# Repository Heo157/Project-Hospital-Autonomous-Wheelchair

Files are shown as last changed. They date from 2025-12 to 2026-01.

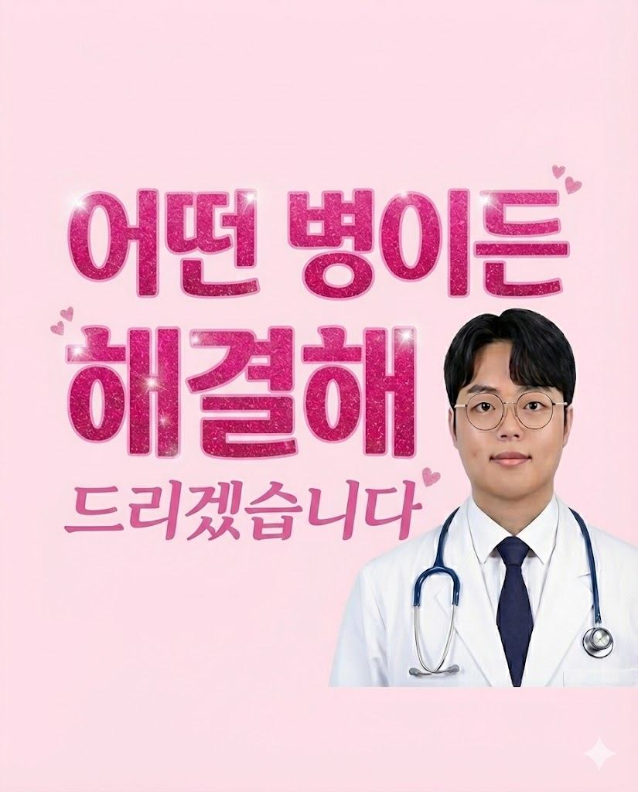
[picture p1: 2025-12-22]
Hospital_WithSTM/Hospital_STM/TouchGFX/assets/images/jinkyoung.png

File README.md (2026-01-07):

# 🏥 Hospital Autonomous Wheelchair Robot  

> **요약**  
> TurtleBot3 Burger 플랫폼에 3D 프린팅 휠체어 구조물을 장착하고,  
> **LiDAR SLAM 기반 자율주행(ROS2/Nav2)** + **중앙 서버/DB 배차 시스템** + **Qt 터치 키오스크(외래 호출)** + **STM32U5(초음파/압력 + Touch-GFX UI)** 를 결합해  
> 병원 환경에서 **환자 호출 → 탑승 확인 → 목적지 이동 → 도착 알림 → 하차/대기/충전** 흐름을 구현하는 프로젝트입니다.
>
> Youtube 영상 : https://youtu.be/OP_KvQtHlb4

---

## 📌 1. 프로젝트 목표

- 병원에서 거동이 불편한 환자가 휠체어를 쉽게 호출하고 이동할 수 있도록 지원
- **외래 환자**는 **터치 키오스크(Qt)** 로 호출
- **입원 환자**는 간호사가 **간호사용(QT)** 로 호출
- 자율주행은 **LiDAR SLAM + Nav2** 로 수행
- **STM32U5G9J-DK2 보드**로:
  - LiDAR가 감지하기 어려운 **낮은 높이 장애물**을 초음파로 감지
  - **압력 센서**로 환자 탑승/하차를 감지하여 서버/DB에 반영
  - 보드 내장 **Touch-GFX**에서 로봇 상태/토픽값을 실시간 UI로 표시

---

## 🔧 2. 하드웨어 구성 

### ✅ Robot Side


### ✅ STM32 Side


---

## ✨ 3. 핵심 기능

### ✅ 자율주행
- SLAM으로 맵 생성
- AMCL로 위치 추정
- Nav2로 경로 계획 및 목표 지점 이동

### ✅ 외래 호출: Qt 터치 키오스크
- 외래 환자가 직접 터치 키오스크에서 “휠체어 호출”
- 출발/목적지 선택(또는 스테이션 기준 호출)
- 호출 정보는 서버/DB에 저장되고, 배차 로직이 로봇을 할당

### ✅ 입원 환자 호출/이동
  - 간호사가 필요에 따라 QT에서 환자에게 휠체어 배정 
  - 병동/병실 등 미리 등록된 위치로 휠체어 로봇 배차 및 이동
    
### ✅ 서버/DB 기반 배차
- DB의 호출 큐(call queue)를 기반으로
  - 가용 로봇 탐색
  - 우선순위 배정
  - 로봇에 start/goal 좌표 전달
  - 로봇 상태를 DB에 지속 기록

### ✅ STM32U5 보드 + Touch-GFX UI
- 초음파(IUM-100): **하단 장착** → 낮은 장애물 감지용
- 압력(FSR): **seat_detected** → 탑승 감지용
- Touch-GFX UI에 ROS 토픽 기반 상태 표시

---

## 🗺️ 4. 동작 시나리오 

### 4.1 외래 환자 호출(키오스크)
1. 외래 환자가 **Qt 키오스크**에서 휠체어 호출
2. 키오스크가 서버/DB에 호출 등록(call queue insert)
3. 서버 Dispatch가 가용 로봇을 선택하여 배차
4. 로봇은 출발지 → 목적지로 Nav2 goal 이동
5. 도착 시 서버/관리자 UI에 알림

### 4.2 입원 환자 호출(병동/병실 기반)
1. 간호사/관리자가 호출(병실/병동 선택)
2. 서버가 DB의 위치(map_location) 좌표를 참조
3. 로봇 배차 후 해당 위치로 이동

### 4.3 탑승/하차 판단(압력 센서)
- STM32U5의 FSR 압력 센서로 `seat_detected = 1/0` 판별
- Raspberry Pi4가 이를 수신하고 서버에 전달하여 DB에 기록

### 4.4 하단 장애물 안전(초음파)
- LiDAR는 보통 바닥 가까운 낮은 장애물을 놓칠 수 있음
- STM32U5 초음파를 하단에 장착하여 `/ultra_distance_cm` publish
- 임계 거리 이하면:
    -Nav2 goal cancel/재계획(설계에 따라)

----

## 🧠 5. 시스템 아키텍처 

### 1) 전체 시스템 아키텍처 


- **Application (Qt)**  
  - 관리자용 Qt / 외래환자용 Qt  / 간호사용 Qt 
- **Database (MariaDB/SQL)**  
  - `robot_status`, `call_queue`, `map_location` 등을 통해 상태 저장 및 배차 데이터 관리
- **Central Server (TCP, C)**  
  - 로봇 접속 관리, 상태 수집, 명령 전달, 배차 로직 수행
- **Platform (ROS2)**  
  - 로봇의 자율주행, 센서 토픽 처리, 서버-로봇 브리지 연동
- **Hardware**  
  - TurtleBot3 Burger + STM32U5 모듈(센서/디스플레이)

---

### 2) 다중 로봇 확장형 배차 구조 (robot_status 기반 최대 N대 운영)


본 시스템은 **DB의 `robot_status` 테이블**을 중심으로 로봇을 관리합니다.

- 로봇 하드웨어가 추가 되다면
  - 서버는 `robot_status`의 `robot_id`(또는 name)를 기준으로 **로봇 호스트를 등록**
  - 로봇 상태를 주기적으로 갱신하고,
  - 호출 큐(`call_queue`)와 매칭해 **배차/명령 할당**을 수행합니다.
- 즉, **로봇이 늘어나도 서버/DB 구조는 동일**하며,
  - `robot_status` 레코드 수만 증가하는 형태로 **최대 100대 까지 확장 가능한 구조**를 목표로 설계했습니다.

---

### 3) STM32U5 + TouchGFX  연동 구조 (ROS 토픽 표시 + 센서 토픽 생성)



STM32U5는 단순 센서 보드가 아니라, **로봇 상태 표시(TouchGFX) + 센서 모듈** 역할을 수행합니다.

#### ✅ A. ROS → STM32U5(TouchGFX) 
Raspberry Pi 4(ROS2)에서 수신/발행 중인 주요 토픽을 STM32U5로 전달하여 TouchGFX에 표시합니다.

| Topic | 의미 | UI 표시 예시 |
|---|---|---|
| `/hostname/amcl_pose` | 맵 기준 현재 위치 | x, y, yaw |
| `/hostname/odom` | odom/속도 | v, w, 누적 |
| `/hostname/battery_state` | 배터리 상태 | %, charging |
| `/hostname/goal_pose` | 목표 좌표 | goal x, y |
| `/hostname/scan` | LiDAR 스캔 | min range |

#### ✅ B. STM32U5 센서 → ROS2 토픽 생성 → STM32U5(TouchGFX) 
STM32U5에 연결된 센서를 통해 ROS2로 전송하여 **추가 토픽을 생성**하고, 로봇 호스트명을 붙여 재발행 하고 STM32U5로 전달하여 TouchGFX에 표시합니다.

- STM32U5 센서 입력:
- | Topic | 의미 | UI 표시 예시 |
  |------|------|-------------|
  | `/hostname/ultra_distance_cm` | 초음파 거리(cm) | min 거리 |
  | `/hostname/seat_detected` | 탑승 감지(0/1) | Seated/Empty |

- 운영 관점:
  - 다중 로봇 환경에서 토픽 충돌을 막기 위해  
    `/<hostname>/ultra_distance_cm`, `/<hostname>/seat_detected` 처럼 **호스트명 구조로 재발행** 

---

## 6. 🧱 Database (MariaDB/MySQL)

### ✅ 주요 테이블 요약

#### 1) `call_queue` — 호출 대기열 (키오스크/시스템 호출 저장)

| 컬럼명 | 설명 | 예시 |
|---|---|---|
| `call_id`  | 호출 ID | 101 |
| `call_time`  | 호출 생성 시간 | 2025-12-31 12:34:56 |
| `caller_name` | 환자/호출자 이름 | "홍길동" |
| `start_loc` | 출발지(장소명 문자열) | "키오스크" |
| `dest_loc` | 목적지(장소명 문자열) | "정형외과" |
| `is_dispatched`  | 배차 여부 | 배차 여부(0/1)|
| `eta`  | 상태/예상 정보 | "이동중" |

#### 2) `map_location` — 장소명 → 좌표 매핑 테이블

| 컬럼명  | 설명 | 예시 |
|---|---|---|
| `location_id`  | 장소 ID | 12 |
| `location_name` | 장소명(문자열) | "진료실 2" |
| `x` | 맵 좌표 X | 1.25 |
| `y` | 맵 좌표 Y | -3.40 |

> 서버 배차 시 `call_queue.start_loc`, `call_queue.dest_loc`을 `map_location`에서 찾아 (x, y)로 변환합니다.

#### 3) `robot_status` — 로봇 상태 + 명령 채널(핵심 테이블)

| 구분 | 컬럼명  | 설명 |
|---|---|---|
| 식별 | `robot_id` | 로봇 고유 ID |
| 식별 | `name`  | 로봇 이름(서버가 로봇 구분에 사용) |
| 네트워크 | `ip_address` | 로봇 IP |
| 상태 | `op_status`  | `WAITING/HEADING/BOARDING/RUNNING/STOP/ARRIVED/EXITING/CHARGING/ERROR` |
| 전원 | `battery_percent` | 배터리 % |
| 전원 | `is_charging` | 충전 중 여부(0/1) |
| 현재 위치 | `current_x` | 현재 X |
| 현재 위치 | `current_y` | 현재 Y |
| 현재 방향 | `current_theta` | 현재 θ(yaw) |
| 시작 좌표 | `start_x`  | 배차된 출발지 X |
| 시작 좌표 | `start_y` | 배차된 출발지 Y |
| 목표 좌표 | `goal_x` | 배차된 목적지 X |
| 목표 좌표 | `goal_y` | 배차된 목적지 Y |
| 센서/기타 | `sensor` | 센서 상태/메모 |
| **명령** | **`order`** | **명령 존재 여부(서버: `order>0`이면 로봇에게 전송)** |
| 호출자 | `who_called` | 호출자 이름 저장 |

> `order`는 서버 → 로봇 명령 전달을 위한 “DB 기반 명령 채널” 역할입니다.

#### 4) `patient_info`, `disease_types` — 우선순위 배차(응급/질병/호출시간)

##### `patient_info` (환자 정보)

| 컬럼(예시) | 설명 |
|---|---|
| `name` | 환자 이름 |
| `disease_code` | 질병 코드 |
| `is_emergency` | 응급 여부(1이면 최우선) |
| `type` | 환자 타입(OUT/IN) |

##### `disease_types` (질병 우선순위 기준)

| 컬럼(예시) | 설명 |
|---|---|
| `base_priority` | 우선순위 점수(클수록 우선) |

✅ **배차 우선순위 정렬**

| 우선순위 | 기준 | 정렬 방향 |
|---|---|---|
| 1 | `is_emergency` | DESC (응급 먼저) |
| 2 | `base_priority` | DESC (점수 높은 질병 먼저) |
| 3 | `call_time` | ASC (먼저 온 호출 먼저) |

---
## 7. 지도
   


---

## 🧰 8. 기술 스택

<div align="center">

<!-- UI -->


<br/>

<!-- Backend -->




<br/>

<!-- Core -->




<br/>

<!-- Hardware -->




<br/>

</div>

---

## 👥9. 팀원 소개 

| &nbsp;&nbsp;&nbsp;&nbsp;이름&nbsp;&nbsp;&nbsp;&nbsp; | &nbsp;&nbsp;&nbsp;&nbsp;역할&nbsp;&nbsp;&nbsp;&nbsp; | 파트 | 담당 기능(요약) | 사용 기술/도구 |
| :---: | :---: | :--- | :--- | :--- |
| **허진경** | 팀장 | Robot / ROS | TurtleBot3 자율주행(ROS2/Nav2/SLAM) 통합, <br>C 서버와 ROS 연결 노드, 미션 수행 로직 구현| ROS2, Nav2, SLAM |
| **강송구** | 부팀장 | Server / DB / Qt / Touch-GFX | C 서버 구현, MariaDB 스키마/쿼리 설계,<br>로봇 상태 저장/배차 로직, ROS 토픽 → Touch-GFX UI 표시 | C(Socket), MariaDB / MySQL, Touch-GFX(STM32) |
| **김선곤** | 팀원 | Qt / Touch-GFX | Qt UI 디자인 전체 구현 <br>STM32U5 Touch-GFX UI 구현 | Qt, Touch-GFX(STM32) |
| **임정민** | 팀원 | DB / ROS | DB 데이터 관리/정리, URDF | MariaDB /ROS2 |
| **유종민** | 팀원 | Firmware /ROS | STM32U5(초음파/압력) 센서 구현 및<br>ROS2 연동, 3D 프린팅 구조물 제작 | ROS2, STM32,Fusion 360 |

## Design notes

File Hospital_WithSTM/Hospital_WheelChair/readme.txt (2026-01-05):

-- 작업 공간
cd ~/ros_ws/src

-- tcp_bridge 패키지 생성
ros2 pkg create wc_server_bridge --build-type ament_python --dependencies rclpy

-- 노드코드
vi wc_server_bridge/wc_server_bridge/tcp_bridge.py

-- setup.py에 entry_points 등록
entry_points={
    'console_scripts': [
        'tcp_bridge = wc_server_bridge.tcp_bridge:main',
    ],
},

-- bringup launch 생성
cd ~/ros_ws/src
ros2 pkg create --build-type ament_python wc_bringup

-- 빌드/실행
cd ~/ros_ws
colcon build
source install/setup.bash
ros2 launch wc_bringup bringup.launch.py

터틀봇 라즈베리 파이-----
dist_seat_topic_pkg 터틀봇 turtlebot3_wc/src/turtlebot3에 이동
robot.launch.py turtlebot3_wc/src/turtlebot3/turtlebot3_bringup/launch안에 복사

$ colcon build --symlink-install
$ source install/setup.bash

ros2 launch turtlebot3_bringup robot.launch.py

//251223 임정민

병원맵 런치 파일
map_gazebo.launch (맵이랑 봇이랑 따로)
cd ~/project/Project-Hospital-Autonomous-Wheelchair/Hospital_WheelChair/hospital_ws
colcon build --symlink-install

터미널1
source /opt/ros/humble/setup.bash
source ~/project/Project-Hospital-Autonomous-Wheelchair/Hospital_WheelChair/hospital_ws/install/setup.bash

export GAZEBO_MODEL_PATH=$GAZEBO_MODEL_PATH:$(ros2 pkg prefix hospital_description)/share
echo $GAZEBO_MODEL_PATH

ros2 launch gazebo_ros gazebo.launch.py

터미널2

source /opt/ros/humble/setup.bash
source ~/project/Project-Hospital-Autonomous-Wheelchair/Hospital_WheelChair/hospital_ws/install/setup.bash

ros2 run gazebo_ros spawn_entity.py \
  -entity hospital_map \
  -file $(ros2 pkg prefix hospital_description)/share/hospital_description/urdf/map_hospital.urdf \
  -x 0 -y 0 -z 0.2

터미널 3
source /opt/ros/humble/setup.bash
source ~/project/Project-Hospital-Autonomous-Wheelchair/Hospital_WheelChair/hospital_ws/install/setup.bash

ros2 run gazebo_ros spawn_entity.py \
  -entity hospital_bot \
  -file $(ros2 pkg prefix hospital_description)/share/hospital_description/urdf/turtlebot3_burger_Hospital_fixed.urdf \
  -x 0.5 -y -1 -z 0.2

++++
터미널 한개로 (hospital_gazebo_spawn.launch.py 로 맵+봇 한번에)
source /opt/ros/humble/setup.bash
source ~/project/Project-Hospital-Autonomous-Wheelchair/Hospital_WheelChair/hospital_ws/install/setup.bash

ros2 launch hospital_description hospital_gazebo_spawn.launch.py

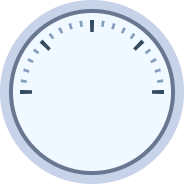
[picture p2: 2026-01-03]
Hospital_WithSTM/Hospital_STM/TouchGFX/assets/images/__generated/clay_theme_images_widgets_gauge_small_backgrounds_active_precision.png

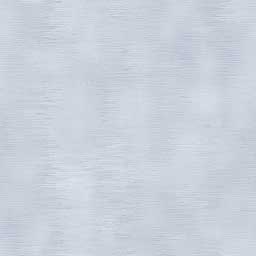
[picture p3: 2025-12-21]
Hospital_WithSTM/Hospital_WheelChair/hospital_ws/src/hospital_description/meshes/sensors/r200.jpg

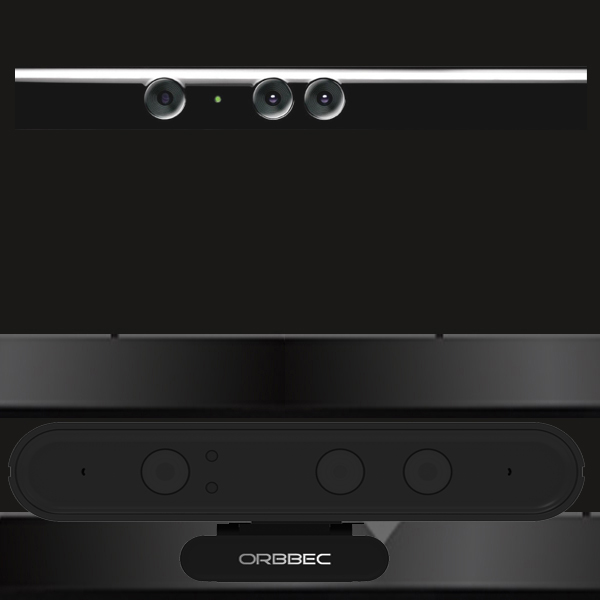
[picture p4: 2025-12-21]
Hospital_WithSTM/Hospital_WheelChair/hospital_ws/src/hospital_description/meshes/sensors/astra.jpg

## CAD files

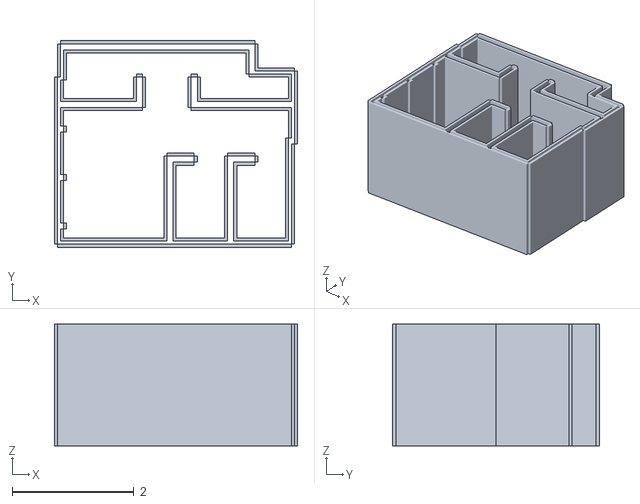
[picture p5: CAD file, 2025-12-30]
Hospital_WithSTM/Hospital_WheelChair/hospital_ws/src/hospital_description/maps/Hospital.stl
4.00 x 3.40 x 2.00

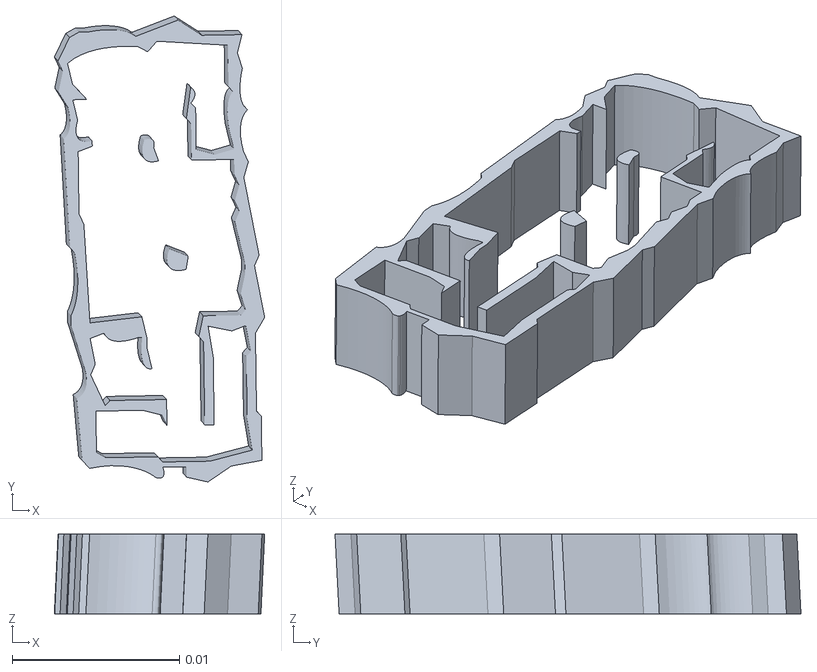
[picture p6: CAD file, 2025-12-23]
Hospital_WithSTM/Hospital_WheelChair/hospital_ws/src/hospital_description/meshes/bases/map_clean.stl
0.0126 x 0.0278 x 0.00477

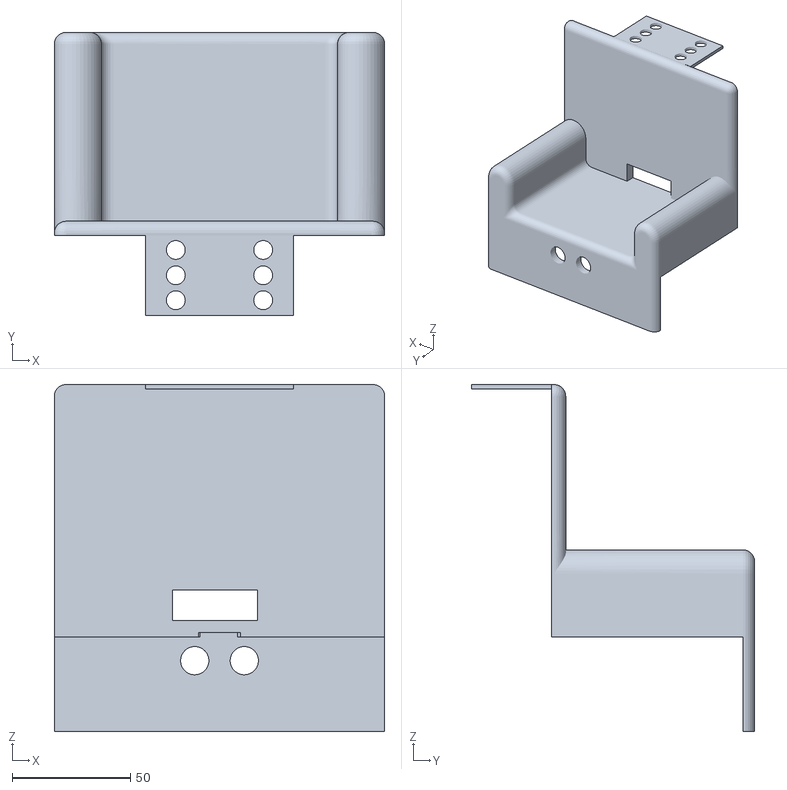
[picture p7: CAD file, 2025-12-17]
Hospital_WithSTM/Hospital_WheelChair/hospital_ws/src/hospital_description/meshes/chair/chair.stl
140.0 x 120.0 x 147.0

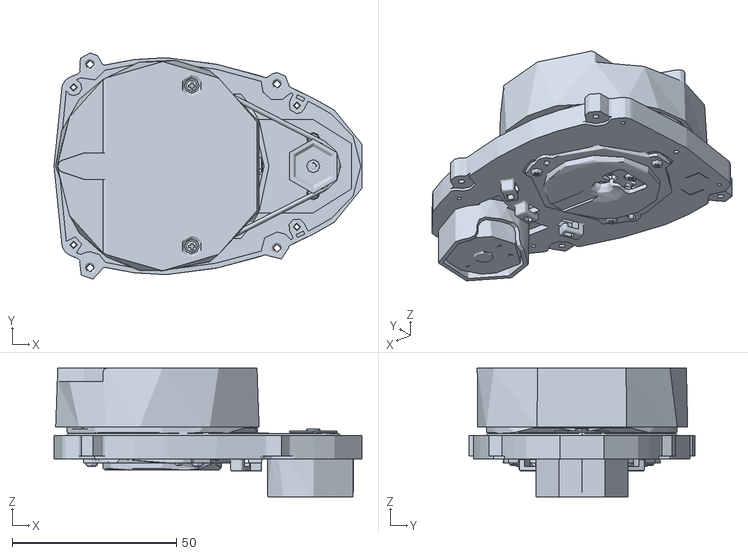
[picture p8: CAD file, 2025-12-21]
Hospital_WithSTM/Hospital_WheelChair/hospital_ws/src/hospital_description/meshes/sensors/lds.stl
93.8 x 68.9 x 39.2

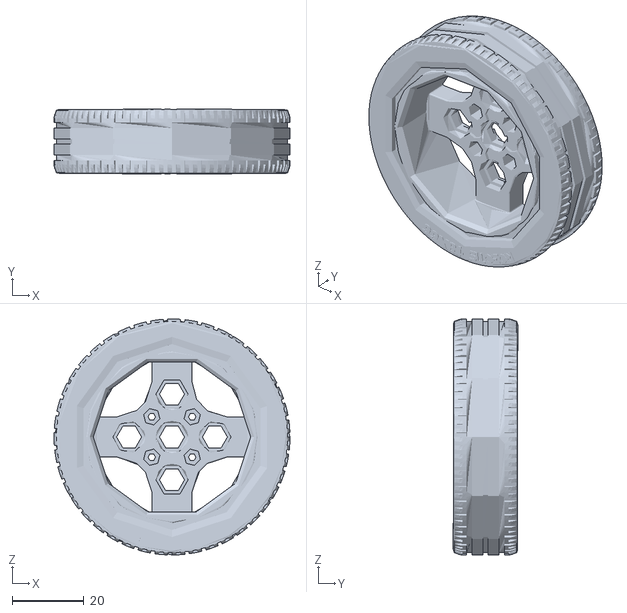
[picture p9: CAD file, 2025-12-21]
Hospital_WithSTM/Hospital_WheelChair/hospital_ws/src/hospital_description/meshes/wheels/right_tire.stl
66.0 x 18.2 x 66.0

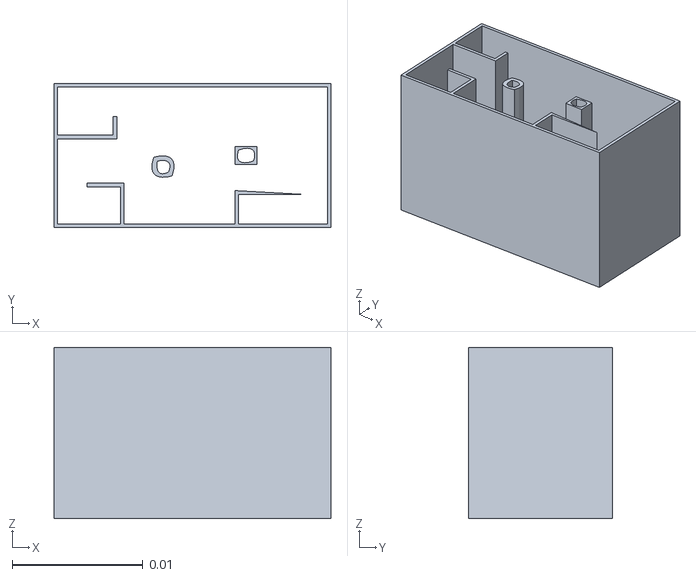
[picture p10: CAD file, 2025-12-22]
SLAM_MAP/hospital_world/meshes/map_Hospital_3D.stl
0.0212 x 0.011 x 0.0131

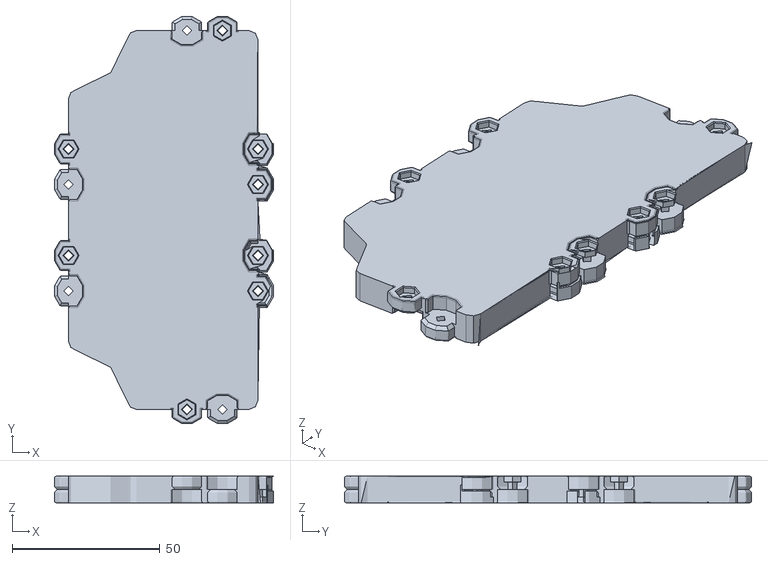
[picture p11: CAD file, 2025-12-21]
Hospital_WithSTM/Hospital_WheelChair/hospital_ws/src/hospital_description/meshes/bases/top_plate.stl
74.0 x 137.5 x 9.00

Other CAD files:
Hospital_WheelChair/hospital_ws/install/hospital_description/share/hospital_description/meshes/bases/burger_base.stl
Hospital_WheelChair/hospital_ws/install/hospital_description/share/hospital_description/meshes/chair/chair.stl
Hospital_WheelChair/hospital_ws/install/hospital_description/share/hospital_description/meshes/bases/waffle_pi_base.stl
Hospital_WithSTM/Hospital_WheelChair/hospital_ws/src/hospital_description/meshes/wheels/left_tire.stl
Hospital_WheelChair/hospital_ws/install/hospital_description/share/hospital_description/meshes/bases/top_plate.stl
Hospital_WheelChair/hospital_ws/install/hospital_description/share/hospital_description/meshes/bases/burger_1.stl
Hospital_WheelChair/hospital_ws/install/hospital_description/share/hospital_description/meshes/bases/burger_5.stl
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

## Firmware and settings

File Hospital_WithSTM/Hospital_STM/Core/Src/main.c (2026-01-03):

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
/* Includes ------------------------------------------------------------------*/
#include "main.h"
#include "jpeg_utils_conf.h"
#include "cmsis_os2.h"
#include "app_touchgfx.h"

/* USER CODE BEGIN Includes */
#include "Components/mx66uw1g45g/mx66uw1g45g.h"
#include <string.h>
#include <stdio.h>
#include <stdlib.h>
#include "common_data.h"
#include "ultrasonic.h"
/* USER CODE END Includes */

ADC_HandleTypeDef hadc4;

CRC_HandleTypeDef hcrc;

DCACHE_HandleTypeDef hdcache1;
DCACHE_HandleTypeDef hdcache2;

DMA2D_HandleTypeDef hdma2d;

GPU2D_HandleTypeDef hgpu2d;

XSPI_HandleTypeDef hxspi1;

I2C_HandleTypeDef hi2c2;

JPEG_HandleTypeDef hjpeg;
DMA_HandleTypeDef handle_GPDMA1_Channel1;
DMA_HandleTypeDef handle_GPDMA1_Channel0;

LTDC_HandleTypeDef hltdc;

TIM_HandleTypeDef htim4;

UART_HandleTypeDef huart1;

/* USER CODE BEGIN PV */
volatile RobotData_t g_robot_data;
volatile ButtonCommand_t g_btn_cmd_queue = BTN_CMD_NONE;
#define RX_BUFFER_SIZE 256
uint8_t rx_byte;                // 1바이트 수신 임시 변수
uint8_t rx_buffer[RX_BUFFER_SIZE]; // 한 문장 저장 버퍼
uint8_t rx_index = 0;
/* USER CODE END PV */

void SystemClock_Config(void);
static void SystemPower_Config(void);
void MX_FREERTOS_Init(void);
static void MX_GPIO_Init(void);
static void MX_GPDMA1_Init(void);
static void MX_ICACHE_Init(void);
static void MX_DCACHE1_Init(void);
static void MX_DCACHE2_Init(void);
static void MX_CRC_Init(void);
static void MX_LTDC_Init(void);
static void MX_DMA2D_Init(void);
static void MX_GPU2D_Init(void);
static void MX_HSPI1_Init(void);
static void MX_I2C2_Init(void);
static void MX_JPEG_Init(void);
static void MX_ADC4_Init(void);
static void MX_TIM4_Init(void);
static void MX_USART1_UART_Init(void);
/* USER CODE BEGIN 0 */
void Parse_Robot_Packet(char* packet)
{
    // strtok를 사용하기 위해 임시 포인터 사용
    char *token;
    char *rest = packet;

    // 1. 모드 (Enum)
    token = strtok_r(rest, "@", &rest);
    if(token == NULL) return;
    int mode_val = atoi(token);
    g_robot_data.current_state = (RobotState_t)mode_val;

    // 2. 속도 (m/s -> km/h 변환)
    token = strtok_r(rest, "@", &rest);
    if(token == NULL) return;
    float speed_ms = strtof(token, NULL);
    g_robot_data.speed_kmh = (int)(speed_ms * 3.6f * 10.0f  + 0.5f);
    // 3. 배터리 (%)
    token = strtok_r(rest, "@", &rest);
    if(token == NULL) return;
    g_robot_data.battery_percent = atoi(token);

    // 4. 호출자 (String)
    token = strtok_r(rest, "@", &rest);
    if(token != NULL) strncpy((char*)g_robot_data.caller_name, token, 63);
    else g_robot_data.caller_name[0] = '\0';

    // 5. 출발지 (String)
    token = strtok_r(rest, "@", &rest);
    if(token != NULL) strncpy((char*)g_robot_data.start_loc, token, 63);
    else g_robot_data.start_loc[0] = '\0';

    // 6. 도착지 (String) - 마지막 토큰은 개행문자(\n) 처리 주의
    token = strtok_r(rest, "@", &rest);
    if(token != NULL) {
        // 개행 문자 제거
        token[strcspn(token, "\r\n")] = 0;
        strncpy((char*)g_robot_data.dest_loc, token, 63);
    }
    else g_robot_data.dest_loc[0] = '\0';

    // UI 업데이트 플래그 설정
    g_robot_data.is_updated = true;
}

// UART 수신 인터럽트 콜백 (1바이트씩 받을 때마다 호출)
void HAL_UART_RxCpltCallback(UART_HandleTypeDef *huart)
{
    if (huart->Instance == USART1)
    {
        // 1. 버퍼 오버플로우 방지 및 저장
        if (rx_index < RX_BUFFER_SIZE - 1) {
            rx_buffer[rx_index] = rx_byte;

            // 2. 개행 문자('\n')를 만나면 패킷 완성으로 간주
            if (rx_buffer[rx_index] == '\n') {
                rx_buffer[rx_index] = '\0'; // 문자열 끝 처리
                Parse_Robot_Packet((char*)rx_buffer); // 파싱 시작
                rx_index = 0; // 인덱스 초기화 (다음 패킷 준비)
            } else {
                rx_index++;
            }
        } else {
            // 버퍼가 꽉 차면 비우기 (에러 처리)
            rx_index = 0;
        }

        // 3. 다음 바이트 수신 인터럽트 재설정
        HAL_UART_Receive_IT(&huart1, &rx_byte, 1);
    }
}
/* USER CODE END 0 */

/**
  * @brief  The application entry point.
  * @retval int
  */
int main(void)
{

  /* MCU Configuration--------------------------------------------------------*/

  /* Reset of all peripherals, Initializes the Flash interface and the Systick. */
  HAL_Init();

  /* Configure the System Power */
  SystemPower_Config();

  /* Configure the system clock */
  SystemClock_Config();

  /* Initialize all configured peripherals */
  MX_GPIO_Init();
  MX_GPDMA1_Init();
  MX_ICACHE_Init();
  MX_DCACHE1_Init();
  MX_DCACHE2_Init();
  MX_CRC_Init();
  MX_LTDC_Init();
  MX_DMA2D_Init();
  MX_GPU2D_Init();
  MX_HSPI1_Init();
  MX_I2C2_Init();
  MX_JPEG_Init();
  MX_ADC4_Init();
  MX_TIM4_Init();
  MX_USART1_UART_Init();
  MX_TouchGFX_Init();
  /* Call PreOsInit function */
  MX_TouchGFX_PreOSInit();
  /* USER CODE BEGIN 2 */
  // UART 인터럽트 수신 시작 (1바이트)
  HAL_UART_Receive_IT(&huart1, &rx_byte, 1);

  // 초기 데이터 더미 값 설정 (디버깅용)
  g_robot_data.current_state = STATE_WAITING;
  g_robot_data.speed_kmh = 0;
  g_robot_data.battery_percent = 100;
  strcpy((char*)g_robot_data.caller_name, "");
  /* USER CODE END 2 */

  /* Init scheduler */
  osKernelInitialize();
  /* Call init function for freertos objects (in app_freertos.c) */
  MX_FREERTOS_Init();

  /* Start scheduler */
  osKernelStart();

  /* We should never get here as control is now taken by the scheduler */

  /* Infinite loop */
  /* USER CODE BEGIN WHILE */
  while (1)
  {
    /* USER CODE END WHILE */

    /* USER CODE BEGIN 3 */
  }
  /* USER CODE END 3 */
}

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
/* USER CODE BEGIN 4 */
void HAL_TIM_IC_CaptureCallback(TIM_HandleTypeDef *htim)
{
    // TIM4에서 인터럽트 발생 시 초음파 계산 함수 호출
    if (htim->Instance == TIM4) {
        Ultrasonic_TIM_IC_CaptureCallback(htim);
    }
}
/* USER CODE END 4 */

/**
  * @brief  Period elapsed callback in non blocking mode
  * @note   This function is called  when TIM6 interrupt took place, inside
  * HAL_TIM_IRQHandler(). It makes a direct call to HAL_IncTick() to increment
  * a global variable "uwTick" used as application time base.
  * @param  htim : TIM handle
  * @retval None
  */
void HAL_TIM_PeriodElapsedCallback(TIM_HandleTypeDef *htim)
{
  if (htim->Instance == TIM6)
  {
    HAL_IncTick();
  }
}

/**
  * @brief  This function is executed in case of error occurrence.
  * @retval None
  */
void Error_Handler(void)
{
  /* USER CODE BEGIN Error_Handler_Debug */
  /* User can add his own implementation to report the HAL error return state */
  __disable_irq();
  while (1)
  {
  }
  /* USER CODE END Error_Handler_Debug */
}
#ifdef USE_FULL_ASSERT
/**
  * @brief  Reports the name of the source file and the source line number
  *         where the assert_param error has occurred.
  * @param  file: pointer to the source file name
  * @param  line: assert_param error line source number
  * @retval None
  */
void assert_failed(uint8_t *file, uint32_t line)
{
  /* USER CODE BEGIN 6 */
  /* User can add his own implementation to report the file name and line number,
     ex: printf("Wrong parameters value: file %s on line %d\r\n", file, line) */
  /* USER CODE END 6 */
}
#endif /* USE_FULL_ASSERT */

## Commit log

2025-11-21 readme 수정
2025-12-04 트리 구조 생성
2025-12-04 트리 구조 추가v2
2025-12-04 구조 변경
2025-12-16 DB 코드 추가
2025-12-16 table 수정
2025-12-17 홍딘경이
2025-12-17 urdf 추가
    [burger_base.stl, chair.stl, lds.stl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]
2025-12-17 잘못올린 파일 삭제
    [burger_base.stl, chair.stl, lds.stl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]
2025-12-17 urdf 설명추가
2025-12-19 3D 모델링
    [wheelchair.stl]
2025-12-21 Add hospital_description package
    [chair.stl, lds.stl, left_tire.stl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]
2025-12-22 urdf 수정
    [turtlebot3_burger_Hospital_fixed.urdf]
2025-12-22 chore: ignore generated urdf artifacts
2025-12-22 ROS launch py
    [robots.yaml]
2025-12-23 db연동 최종작업 완료
2025-12-23 3D map
    [map_clean.stl]
2025-12-23 lunch 파일
    [map_hospital.urdf]
2025-12-23 Revise README with updated build and launch instructions
    Updated instructions for building and launching the hospital wheelchair project, including terminal commands and environment setup.
2025-12-23 경로수정
2025-12-23 경로이동
2025-12-23 터미널 하나로 맵+봇
2025-12-23 긴급 패치
2025-12-23 db 추가
2025-12-26 add robot ssh, fix server with process
    [main.c]
2025-12-27 Update function signatures in server_db.h
    원래꺼 살림
2025-12-28 C 서버 및 파이썬 브리지 코드 수정 완료
2025-12-29 찐막 맵
2025-12-30 ros_pi추가
2025-12-30 install 추가
2026-01-02 찐찐막 맵
2026-01-02 add stm
    [Hospital.stl, chair.stl, lds.stl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]
2026-01-03 yjm추가
2026-01-03 FSR 임계값 변경_YJM
2026-01-03 제발 찐막이여라
2026-01-03 fix stm32_bridge

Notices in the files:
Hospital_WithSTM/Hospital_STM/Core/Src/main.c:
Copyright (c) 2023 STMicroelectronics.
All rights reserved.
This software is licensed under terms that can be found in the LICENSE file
